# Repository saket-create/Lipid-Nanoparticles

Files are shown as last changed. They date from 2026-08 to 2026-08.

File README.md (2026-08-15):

# Lipid-Nanoparticles

This project focuses on developing a low-cost, lab-scale LNP manufacturing system using open-source hardware, 3D-printed components, and controlled multi-stream mixing.
this project is done in two steps:

**Semester Work**
This phase of the project involved developing the foundational process understanding through **simulation** and **flow diagram development**, along with research into **Process Analytical Technology (PAT)**. It also included the creation of the **P&ID** and completion of a preliminary **HAZOP analysis**, followed by the initial design of the mixing system and overall process layout.
A **Python library for LNP composition and process simulation** was also developed, incorporating different formulation variations along with a user manual for the simulation tools.

**Summer Work**
In this section i introduced the theoretical part to applied lab where I proceed with **Fabrication and assembly** of four syringe pumps based on the Poseidon open-source design, integrated with an **Arduino, CNC Shield V3, and A4988 stepper motor** drivers using the AccelStepper library for precise control. The work also included **experimental calibration of syringe pump** flow rates, where different settings were tested and tuned to achieve consistent output, along with the design and 3D printing of a **Multi-Inlet Vortex Mixer (MIVM)** to improve mixing efficiency. The system was further refined through iterative testing, troubleshooting, and optimization of both pumping and mixing performance, with each iteration helping to improve accuracy, stability, and overall system reliability.

This repository contains the **CAD files, Arduino code, experimental data, process documentation, and project resources** developed throughout the project. It serves as a project record, technical handover, and portfolio of the work.

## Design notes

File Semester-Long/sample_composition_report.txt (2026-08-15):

  LNP COMPOSITION & MASS REPORT
  Run ID : 050    |    Timestamp : 2026-04-06  09:04:29
  Calculation mode : FORWARD (feed streams → derived streams)

  mass_flow (mg/min) = concentration (mg/mL) x flow_rate (mL/min)
  TFF separation uses realistic efficiency fractions (see table below).

  TFF SEPARATION EFFICIENCIES
  Component                             Retained (retentate)   Removed (permeate)
  Cholesterol                                            98%                   2%
  Citric Acid                                             2%                  98%
  DSPC (Phospholipid)                                    98%                   2%
  EDTA                                                    2%                  98%
  Ethanol                                                 5%                  95%
  Ionisable Lipid (SM-102/MC3)                           98%                   2%
  Dibasic Sodium Phosphate                                2%                  98%
  Sodium Chloride (NaCl)                                  2%                  98%
  Monobasic Sodium Phosphate                              2%                  98%
  PEG-DMG / PEG-Lipid                                    98%                   2%
  Sodium Citrate                                          2%                  98%
  Water                                                  10%                  90%
  mRNA                                                   95%                   5%

  AQUEOUS PHASE  (mRNA + Buffer, Pump P-101)
  Flow rate : 9.0000 mL/min

  Component                             Conc (mg/mL)   Mass Flow (mg/min)  Source
  mRNA                                        0.1000               0.9000  (user input)
  Citric Acid                                 8.4000              75.6000  (user input)
  Sodium Citrate                              5.9000              53.1000  (user input)
  EDTA                                        0.1900               1.7100  (user input)
  Water                                     985.0000            8865.0000  (user input)

  ORGANIC PHASE  (Lipids in Ethanol, Pump P-102)
  Flow rate : 3.0000 mL/min

  Component                             Conc (mg/mL)   Mass Flow (mg/min)  Source
  Ionisable Lipid (SM-102/MC3)               10.0000              30.0000  (user input)
  DSPC (Phospholipid)                         2.5900               7.7700  (user input)
  Cholesterol                                 1.4800               4.4400  (user input)
  PEG-DMG / PEG-Lipid                         0.4500               1.3500  (user input)
  Ethanol                                   789.0000            2367.0000  (user input)

  DILUTION BUFFER  (PBS / Buffer, T-105)
  Flow rate : 36.0000 mL/min

  Component                             Conc (mg/mL)   Mass Flow (mg/min)  Source
  Sodium Chloride (NaCl)                      8.0000             288.0000  (user input)
  Dibasic Sodium Phosphate                    1.4400              51.8400  (user input)
  Monobasic Sodium Phosphate                  0.2400               8.6400  (user input)
  Water                                     990.0000           35640.0000  (user input)

  CRYOPROTECTANT FEED  (Trehalose/Sucrose, T-100)
  Flow rate : 0.5000 mL/min

  Component                             Conc (mg/mL)   Mass Flow (mg/min)  Source
  Trehalose / Sucrose (Cryoprotectant)       200.0000             100.0000  (user input)
  Water                                     800.0000             400.0000  (user input)

  MIXER OUTPUT  (Crude LNP Dispersion, M-101)
  Flow rate : 12.0000 mL/min

  Component                             Conc (mg/mL)   Mass Flow (mg/min)  Source
  Cholesterol                                 0.3700               4.4400  (calculated)
  Citric Acid                                 6.3000              75.6000  (calculated)
  DSPC (Phospholipid)                         0.6475               7.7700  (calculated)
  EDTA                                        0.1425               1.7100  (calculated)
  Ethanol                                   197.2500            2367.0000  (calculated)
  Ionisable Lipid (SM-102/MC3)                2.5000              30.0000  (calculated)
  PEG-DMG / PEG-Lipid                         0.1125               1.3500  (calculated)
  Sodium Citrate                              4.4250              53.1000  (calculated)
  Water                                     738.7500            8865.0000  (calculated)
  mRNA                                        0.0750               0.9000  (calculated)

  TFF RETENTATE  (Purified Concentrated LNP, UF-101)
  Flow rate : 8.0000 mL/min

  Component                             Conc (mg/mL)   Mass Flow (mg/min)  Source
  Cholesterol                                 0.5439               4.3512  (calculated)
  Citric Acid                                 0.1890               1.5120  (calculated)
  DSPC (Phospholipid)                         0.9518               7.6146  (calculated)
  EDTA                                        0.0043               0.0342  (calculated)
  Ethanol                                    14.7937             118.3500  (calculated)
  Ionisable Lipid (SM-102/MC3)                3.6750              29.4000  (calculated)
  Dibasic Sodium Phosphate                    0.1296               1.0368  (calculated)
  Sodium Chloride (NaCl)                      0.7200               5.7600  (calculated)
  Monobasic Sodium Phosphate                  0.0216               0.1728  (calculated)
  PEG-DMG / PEG-Lipid                         0.1654               1.3230  (calculated)
  Sodium Citrate                              0.1327               1.0620  (calculated)
  Water                                     556.3125            4450.5000  (calculated)
  mRNA                                        0.1069               0.8550  (calculated)

  TFF PERMEATE  (Waste Stream, UF-101)
  Flow rate : 40.0000 mL/min

  Component                             Conc (mg/mL)   Mass Flow (mg/min)  Source
  Cholesterol                                 0.0022               0.0888  (calculated)
  Citric Acid                                 1.8522              74.0880  (calculated)
  DSPC (Phospholipid)                         0.0039               0.1554  (calculated)
  EDTA                                        0.0419               1.6758  (calculated)
  Ethanol                                    56.2162            2248.6500  (calculated)
  Ionisable Lipid (SM-102/MC3)                0.0150               0.6000  (calculated)
  Dibasic Sodium Phosphate                    1.2701              50.8032  (calculated)
  Sodium Chloride (NaCl)                      7.0560             282.2400  (calculated)
  Monobasic Sodium Phosphate                  0.2117               8.4672  (calculated)
  PEG-DMG / PEG-Lipid                         0.0007               0.0270  (calculated)
  Sodium Citrate                              1.3009              52.0380  (calculated)
  Water                                    1001.3625           40054.5000  (calculated)
  mRNA                                        0.0011               0.0450  (calculated)

  FINAL PRODUCT  (Sterile LNP Formulation, ST-101)
  Flow rate : 8.0000 mL/min

  Component                             Conc (mg/mL)   Mass Flow (mg/min)  Source
  Cholesterol                                 0.5439               4.3512  (calculated)
  Citric Acid                                 0.1890               1.5120  (calculated)
  DSPC (Phospholipid)                         0.9518               7.6146  (calculated)
  EDTA                                        0.0043               0.0342  (calculated)
  Ethanol                                    14.7937             118.3500  (calculated)
  Ionisable Lipid (SM-102/MC3)                3.6750              29.4000  (calculated)
  Dibasic Sodium Phosphate                    0.1296               1.0368  (calculated)
  Sodium Chloride (NaCl)                      0.7200               5.7600  (calculated)
  Monobasic Sodium Phosphate                  0.0216               0.1728  (calculated)
  PEG-DMG / PEG-Lipid                         0.1654               1.3230  (calculated)
  Sodium Citrate                              0.1327               1.0620  (calculated)
  Trehalose / Sucrose (Cryoprotectant)        12.5000             100.0000  (calculated)
  Water                                     606.3125            4850.5000  (calculated)
  mRNA                                        0.1069               0.8550  (calculated)

  COMPONENT-WISE MASS BALANCE  (TFF level: inputs = retentate + permeate)

  Component                                Mass In     Mass Out      Error  Status
  Cholesterol                               4.4400       4.4400     0.0000  PASS
  Citric Acid                              75.6000      75.6000     0.0000  PASS
  DSPC (Phospholipid)                       7.7700       7.7700     0.0000  PASS
  EDTA                                      1.7100       1.7100     0.0000  PASS
  Ethanol                                2367.0000    2367.0000     0.0000  PASS
  Ionisable Lipid (SM-102/MC3)             30.0000      30.0000     0.0000  PASS
  Dibasic Sodium Phosphate                 51.8400      51.8400     0.0000  PASS
  Sodium Chloride (NaCl)                  288.0000     288.0000     0.0000  PASS
  Monobasic Sodium Phosphate                8.6400       8.6400     0.0000  PASS
  PEG-DMG / PEG-Lipid                       1.3500       1.3500     0.0000  PASS
  Sodium Citrate                           53.1000      53.1000     0.0000  PASS
  Water                                 44505.0000   44505.0000     0.0000  PASS
  mRNA                                      0.9000       0.9000     0.0000  PASS

  Mass balance: ALL COMPONENTS BALANCED

  END OF COMPOSITION REPORT

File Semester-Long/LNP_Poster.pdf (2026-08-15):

# Developing a Process Simulation Model for Lipid Nano-particle Manufacturing

## Aman Bola 24110032 | Rhythem Soni 24110296 | Saket Jonwal 24110311 Supervisor: Professor Kaustubh S. Rane

### Motivation & Background

mRNA vaccines (Pfizer-BioNTech, Moderna) saved millions of lives. Their secret ingredient: Lipid Nanoparticles (LNPs) - tiny spheres that protect and deliver mRNA into human cells.

### Lipid Nano-particles

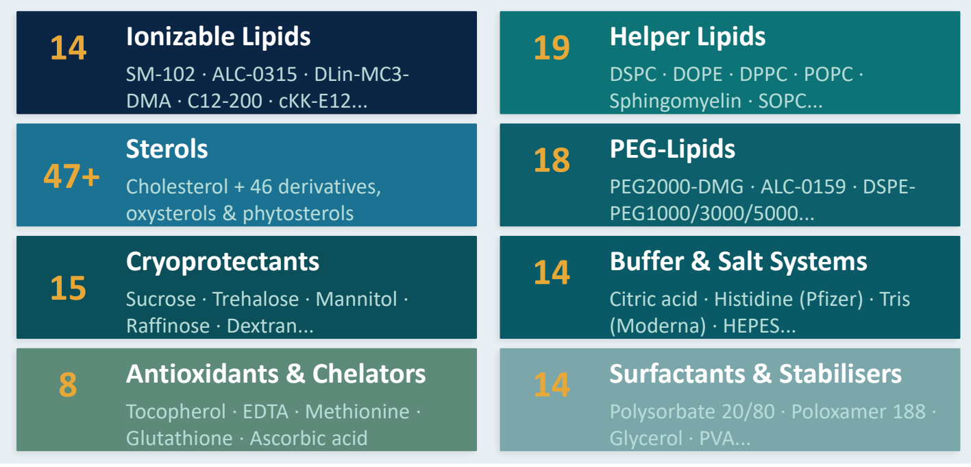
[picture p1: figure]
Ionizable Lipids; SM-102 · ALC-0315 · DLin-MC3- DMA · C12-200 · cKK-E12...; Helper Lipids; DSPC · DOPE · DPPC · POPC · Sphingomyelin · SOPC...; Sterols; Cholesterol + 46 derivatives, oxysterols & phytosterols; PEG-Lipids; PEG2000-DMG · ALC-0159 · DSPE- PEG1000/3000/5000...; Cryoprotectants; Sucrose · Trehalose · Mannitol · Raffinose · Dextran...; Buffer & Salt Systems; Citric acid · Histidine (Pfizer) · Tris (Moderna) · HEPES...; Antioxidants & Chelators; Tocopherol · EDTA · Methionine · Glutathione · Ascorbic acid; Surfactants & Stabilisers; Polysorbate 20/80 · Poloxamer 188 · Glycerol · PVA...

### Process Analytical Technology (PAT)

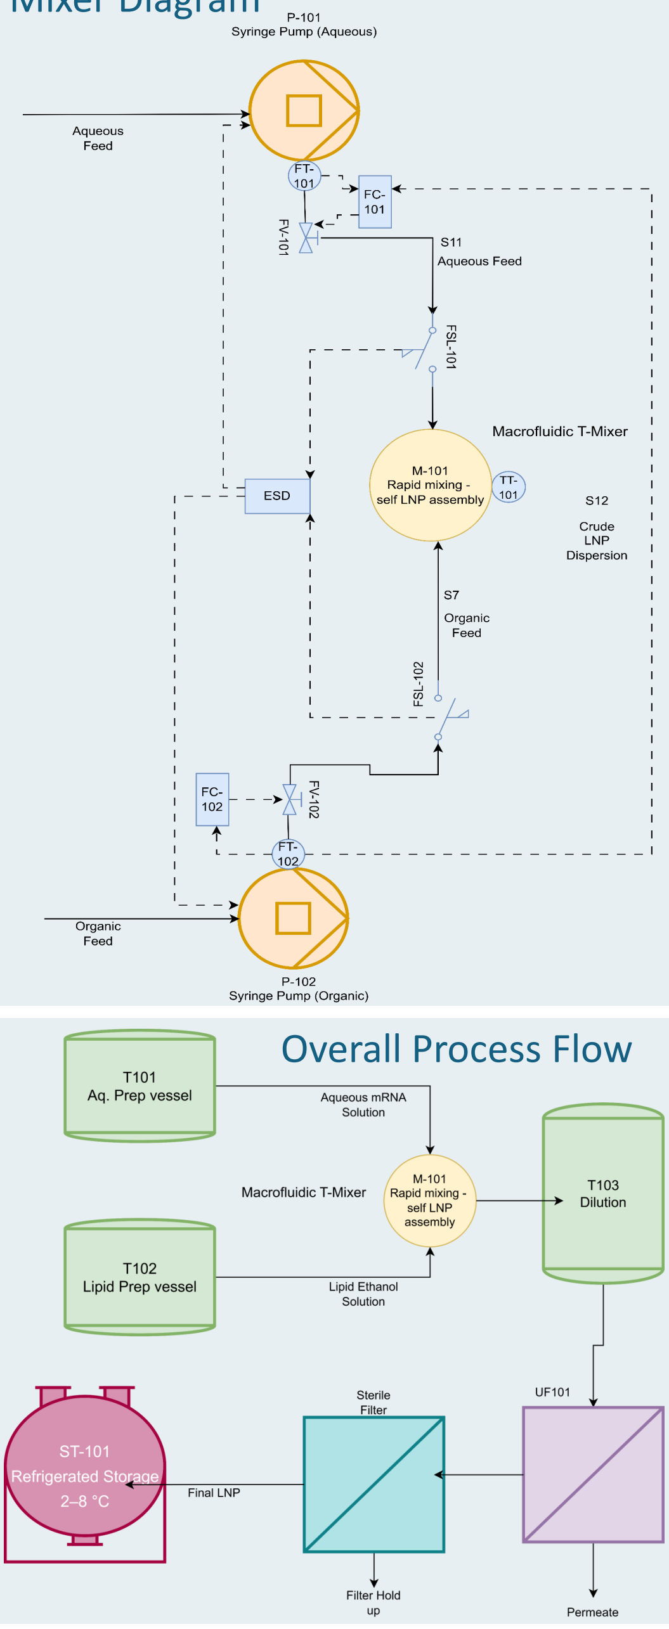
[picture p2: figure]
Overall Process Flow

The FDA defines PAT as a system to analyze, monitor, and control pharmaceutical manufacturing processes in real time. We applied PAT by designing a P&ID with real control loops not just offline testing.

### Challenges

LNP production involves dozens of interlinked variables-flow rates, lipid ratios, pH, filtration pressures - making it extremely complex to design and scale up. So, we need an easy-to-use tool to calculate all process quantities.

### Our Solution

We built a process simulation model that handles all these calculations for you.

- LNPs are tiny, spherical particles made of lipids of size - (10nm - 100nm).
- They encapsulate and protect fragile molecules like mRNA to reach and enter in cells efficiently.
- Ionizable lipid: binds RNA and enables endosomal escape.
- Phospholipid: provides structural stability.
- Cholesterol: improve membrane rigidity and integrity.
- PEG-lipid: prevents aggregation and improves circulation time.

### LNP Component Library (150+ Compounds)

We catalogued every compound used in LNP manufacturing from published patents and scientific literature, with molecular weights and clinical annotations:

FOUR MEASUREMENT LEVELS:

INLINE

Real-time, no sample removal.
Eg: DLS, Zeta potential ,pH sensor, Conductivity, Flow meter, Temperature probes, Pressure probs.

ONLINE

ATLINE

OFFLINE

Near real-time, automated sample removal
Eg: HPLC, Raman spectroscopy, LC-MS, UV diode array. Manual sample removal near production line.
Eg: DLS, Zeta potential, NMR.
Sample removed to separate lab.
Eg: Cryo-TEM.

Focus on identifying two basis:
1) CQAs (Critical Quality Attributes). Eg: Size <100 nm, PDI <0.3.
2) CPPs (Critical Process Parameters). Eg: Flow, Temperature, Pressure etc.

### Key Software Feature

Three Calculation Modes: FORWARD (feeds → product), BACKWARD (desired product → required feeds), or BOTH simultaneously.

DOF Analysis: Automatically checks the Degrees of Freedom. Alerts user if the system is under- or over-specified before solving.

Self-Consistency Check: If concentration AND mass flow are both given for the same component, the software verifies they are consistent with the flow rate.

Warnings & Validation: Flags physically impossible values (e.g. negative flows), out-of-range conditions, and concentration/mass mismatches with severity levels.
Material Balance Verification: Checks that total mass IN equals total mass OUT for every component at TFF level. Reports PASS/FAIL per component. Knowability Scoring: In over-determined cases, automatically selects which variable to treat as redundant, based on how directly measurable each is.

Run History & Reports: Every run is saved in a timestamped folder: output report, diagnostics file, and a copy of the input used.

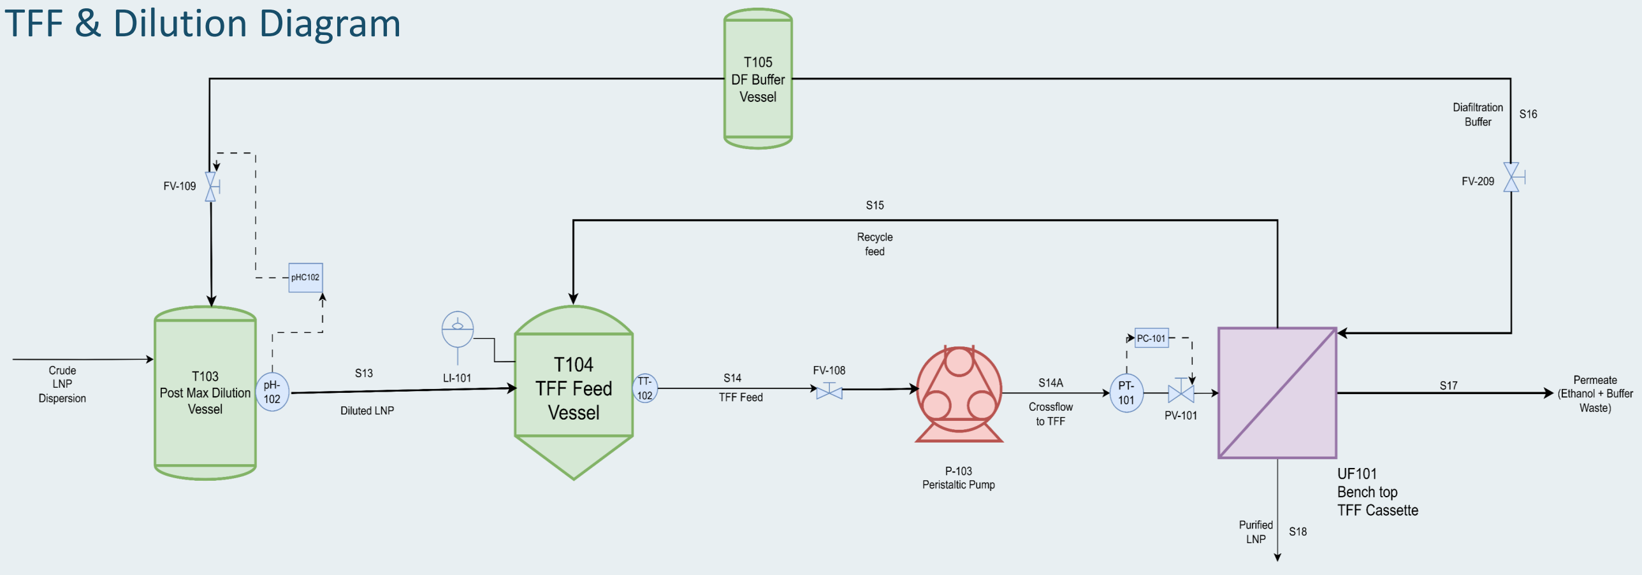
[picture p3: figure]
TFF & Dilution Diagram

### Future Work

- Particle Size Prediction: Add empirical correlations: FRR + total flow rate →
predicted | LNP | size | and | PDI.
- Experimental Validation: Verify all model predictions against physical LNP synthesis runs in the laboratory.
- Digital Twin: Connect PAT sensor feeds to simulation in real-time - close the loop between model and process.
- DoE Optimisation Module: Automated formulation screening → find optimal lipid ratios for target CQAs.
- Scale-Up Calculator: Extend from lab syringe pumps to industrial IJM (KNAUER) and NxGen (Precision Nanosystems) systems.

### Acknowledgement

We are sincerely grateful to our supervisor, Prof. Kaustubh S. Rane, for his invaluable guidance and mentorship.

### Mixer Diagram

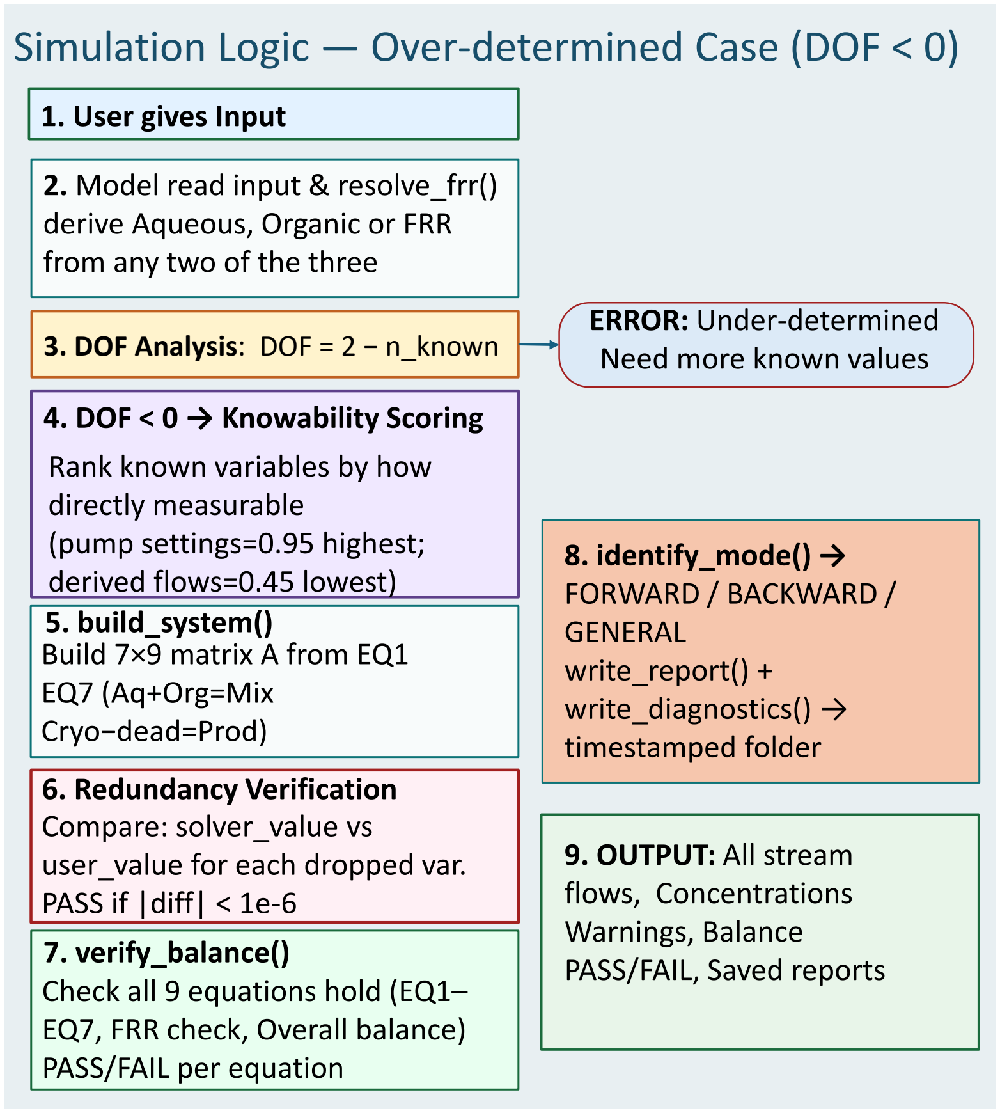
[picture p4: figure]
1. User gives Input; 2. Model read input & resolve_frr() derive Aqueous, Organic or FRR from any two of the three; 3. DOF Analysis: DOF = 2 − n_known; ERROR: Under-determined Need more known values; 4. DOF < 0 → Knowability Scoring; Rank known variables by how directly measurable (pump settings=0.95 highest; derived flows=0.45 lowest) 5. build_system() Build 7×9 matrix A from EQ1 EQ7 (Aq+Org=Mix Cryo−dead=Prod); 6. Redundancy Verification Compare: solver_value vs user_value for each dropped var. PASS if |diff| < 1e-6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

### Simulation Logic — Over-determined Case (DOF < 0)

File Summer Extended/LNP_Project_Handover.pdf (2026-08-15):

# Lab-Scale Lipid Nanoparticle (LNP) Manufacturing

## Project Document

Indian Institute of Technology Gandhinagar Supervisor: Prof. Kaustubh S. Rane Team: Aman Bola 24110032,
Rhythem Soni 24110296,
Saket Jonwal 24110311

Purpose of this document: This document records what has been done on this project to date, why each decision was made, what data/resources exist, and what the open problems and recommended next steps are.

## 1. Project Overview

The goal of this project is to build a lab-scale, low-cost manufacturing setup for lipid nanoparticles (LNPs) using microfluidic mixing. LNPs are the delivery vehicles used for mRNA vaccines and other nucleic-acid therapeutics, and their manufacture at lab scale conventionally relies on expensive commercial microfluidic systems (e.g. NanoAssemblr). The aim of this project is to replicate the core functionality of such a system, controlled multistream mixing of an aqueous phase and a lipid/ethanol phase using open-source hardware and 3D-printed parts, so that LNP formulation work can be done in-house at a fraction of the cost.

The overall system has two halves that had to be built in parallel:

- A set of syringe pumps that can deliver precise, controllable, pulsation-free flow rates for each inlet stream.
- A mixer geometry (the actual mixing chamber) that brings the streams together under turbulent/vortex conditions so that nanoprecipitation happens reproducibly.
Below is a chronological account of the work, organized by workstream.

## 2. Process Simulation Model and Process Flow Diagram

Early in the project, a process simulation model was built to map out the overall LNP manufacturing process conceptually (feed streams, mixing step, downstream dialysis/purification, and characterization steps) before committing to hardware. The process simulation model is there in the final_zip.zip file and you can find it in the google drive. There is a detailed user manual in it which will give complete detail about the model.

A process flow diagram (PFD) of the full process was also created, drawn using draw.io. This PFD is the singlepage reference for how material flows through the system end-to-end (solvent/antisolvent prep → pumps → mixer → collection → downstream processing) and should be consulted first by anyone new to the project to understand where the hardware described in this document sits in the overall workflow. It is also attached in the google drive.

## 3. Process Analytical Technology (PAT) Research

Before finalizing the hardware approach, the team researched Process Analytical Technology (PAT), the general framework (promoted heavily by FDA/ICH guidance for pharmaceutical manufacturing) of building measurement and control directly into a process rather than relying purely on end-product testing. For LNP manufacturing specifically, this means thinking about in-line or at-line monitoring of things like flow rate, particle size (e.g. via in-line DLS), and mixing quality, rather than only characterizing the final product after the fact.

This research shaped two decisions downstream: (1) the emphasis on rigorously calibrating flow rate at the pump level rather than trusting motor step counts blindly, and (2) keeping the mixer design modular enough that in-line sensors could plausibly be added later (e.g. at the outlet tubing).

## 4. Syringe Pump Development

## 4.1 Reference design: Poseidon Github Repository

The syringe pump hardware is based on the open-source Poseidon syringe pump project. This was chosen over designing a pump from scratch because it is a mature, well-documented open-source design with an existing STL/CAD library and firmware base, which significantly reduced development time.

Repository link: https://github.com/pachterlab/poseidon/tree/release

## 4.2 Fabrication

- The Poseidon pump body and carriage parts were 3D printed in the Tinkerer’s Lab.
- Remaining mechanical/electrical components (leadscrews, couplers, NEMA stepper motors, linear rods/bearings, CNC Shield V3 boards, A4988 stepper drivers, Arduino Uno/Nano boards, CH340-based USB-serial boards) were ordered. We have attached the purchase list in the google drive for further reference.
- Four pump units were assembled in total, following the Poseidon assembly instructions, to eventually supply the four inlets of the MIVM. There is a detailed video in the Poseidon repository for the assembly.
- NOTE: In google drive we have attached the modified base for syringe pump model as earlier it was facing screw fixing issues however for other parts to print you have to follow the Poseidon Github Repository.

## 4.3 Control electronics and firmware

Each pump is driven by an Arduino + CNC Shield V3 + A4988 driver stack, controlled using the AccelStepper library for smooth, non-blocking acceleration/deceleration motion profiles. Firmware was written so that a controlling PC can send serial commands (move-to targets, speed) and the pump executes them. The code for Arduino is attached in the google drive (for only X and Z axis of CNC shield and for all four connection you need to repeat the same code for Y and A axis).

Two of the four pumps have been calibrated so far (see Section 5); the other two are built but calibration is still pending because those two motors were not good.

## 5. Syringe Pump Calibration

Calibration methodology: flow rate was determined gravimetrically rather than by trusting the theoretical steps-permL conversion computed from syringe diameter and leadscrew pitch. This mirrors the calibration approach described in the referenced eNeuro paper (ENEURO.0240-19.2019), which was used as a methodological reference for how to rigorously validate syringe-pump flow rate against motor step rate.

The general procedure used for each calibration run:

- The acceleration and the maximum speed parameters (steps/sec² and steps/sec, set in the AccelStepper firmware) were kept fixed for a given pump; the actual run speed for each trial was set at or below this ceiling.
- The pump was run to dispense water into a pre-weighed vessel.
- The mass of water dispensed was measured directly using a weighing machine.
- The time taken to dispense that water was measured independently using a stopwatch.
- Flow rate was then calculated from these two measurements using the mass–density–volume relation (volume = mass / density of water, at ~0.976 g/mL, temperature-adjusted) and flow rate = volume / time.
- This was repeated across a range of run speeds, from ~420 steps/sec up to ~1050 steps/sec, to build a speed → flow-rate calibration curve for each pump.
The calibration data for both the pumps is attached in the google drive in the form of excel sheets.

Observed working range: at the acceleration setting used (200 steps/sec²), motor speeds from ~420 to ~1050 steps/sec produced flow rates from roughly 63 mL/min to 140 mL/min on the calibrated pumps. The relationship between speed and flow rate is close to linear over this range but should be fitted properly (linear regression) rather than assumed, and re-validated whenever syringe diameter, leadscrew, or tubing is changed.

Note: the literature-recommended per-inlet flow rate range for MIVM operation, per Markwalter & Prud'homme (2018) and Zhang & Clapp (2014), is 20–125 mL/min; the target total flow rate (TFR) for our MIVM is 250–300 mL/min across four inlets. This means the pumps need to be run well down their speed range (not near the top of the ~420–1050 steps/sec range tested) to hit realistic per-inlet flow rates for LNP formulation trials.

Important limitation: calibration in the literature-relevant 20–125 mL/min range has not yet been completed. At the lower speeds this range corresponds to, the pump produced noticeable jerking. The root cause identified was that the syringe available was slightly larger than the pump model's syringe holder was designed for, so it had to be forced into place; this small dimensional mismatch is what produces the jerking, and it becomes more noticeable at lower speeds. The fix identified (but not yet carried out) is to rub the syringe holder area of the printed pump model by sanding or filing it down with sandpaper or a metal file so the minor dimensional excess is removed and the syringe seats properly without being forced. Once this is done, the pump should run smoothly at lower speeds, and calibration in the actual 20–125 mL/min operating range should be carried out as a priority.

A separate vibration issue was also observed with the pump body during operation. This was resolved (as a practical fix, not a design fix) by applying double-sided tape to the underside of the pump base and mounting the pump on a rubber sheet, which damps the vibration. This fix should be replicated across all four pump units.

## 6. Micromixer Development

## 6.1 Initial approach: Y/T-mixer

The first mixer concept explored was an open-groove Y-mixer / T-mixer design. This was abandoned because it requires microchannels (sub-mm scale) to achieve adequate mixing, and the campus 3D printers available to the team could not reliably resolve channels at that scale, prints either failed to resolve the channel geometry or produced channels too rough/blocked to be usable.

## 6.2 Shift to MIVM (Multi-Inlet Vortex Mixer)

Given the fabrication constraint above, the design was shifted to a Confined Impinging Jets (CIJ) / Multi-Inlet Vortex Mixer (MIVM) design, which achieves rapid turbulent mixing in a larger, more printable chamber (mm-scale rather than sub-mm channels), while still giving the mixing intensity needed for nanoprecipitation.

The design mainly follows: Markwalter, C.E. & Prud'homme, R.K., "Design of a Small-Scale Multi-Inlet Vortex Mixer for Scalable Nanoparticle Production and Application to the Encapsulation of Biologics by Inverse Flash NanoPrecipitation," J. Pharm. Sci. (2018), the supplementary information document supplied with this handover (1-s2_0-S0022354918303071-mmc1.docx).

## 6.3 Scaling the dimensions

The supplementary information provides dimensions for the small μMIVM design (chamber diameter 0.5 cm, channel height/width 0.075 cm each), plus dimensions for the original, larger benchtop MIVM (chamber diameter 0.6 cm, channel height 0.15 cm). It also gives the scaling relation used to relate chamber diameter to channel width across mixer sizes:

Dc1² / w1 = Dc2² / w2 (Eqn. S1, Markwalter & Prud'homme 2018)

where subscript 1 refers to the original MIVM and subscript 2 refers to the scaled (μMIVM-style) design. This relation was used to back-calculate a self-consistent set of dimensions for our printable mixer, since the paper's exact μMIVM channel width (0.75 mm) was still below our printer's reliable minimum feature size.

The Autodesk file for the mixer model is attached in the google drive and you can we have also made some variations in a few dimensions which you can see from the 3D model.

Target operating point for this geometry: total flow rate (TFR) of 250–300 mL/min split across the four inlets.

## 6.4 Fabrication and materials

The mixer was 3D printed in PETG. PETG was chosen after researching solvent compatibility with pure ethanol (the typical organic/lipid-carrying solvent stream), drawing on Kaptan (2025), Grzelak (2021), Roberson (2019), Plaskolite's TEC409 chemical resistance data, and ORNL/TM-2012/88: PETG shows good short-to-medium-term resistance to ethanol at the concentrations and contact times relevant here.

## 7. Current Status and Open Issues

## 7.1 Syringe pump hardware/firmware

- Only 2 of 4 pumps are calibrated, and even that calibration only covers ~420–1050 steps/sec — it does not yet cover the literature-relevant 20–125 mL/min per-inlet range, because of the syringe-fit jerking issue described in Section 5. Fixing the syringe holder fit (sanding/filing) and then calibrating at lower speeds is a priority open task.
- The acceleration and the deceleration part is not accounted for in the calibration. That means the pump does not operate at constant speed throughout. Instead, it first accelerated, then moved at constant speed, and then it decelerated to stop. So, this acceleration/deceleration time needs to be calibrated.

## 7.2 Mixer

- There are leakages observed in the mixer model which need to be solved by applying a proper sealant.

## 8. Key References and Resources

- Poseidon open-source syringe pump project (GitHub): (https://github.com/pachterlab/poseidon/tree/release) mechanical/firmware base for all four pumps.
- eNeuro paper, ENEURO.0240-19.2019: (https://www.eneuro.org/content/6/5/ENEURO.0240-19.2019#abstract-1) reference for gravimetric syringe pump calibration methodology.
- Markwalter, C.E. & Prud'homme, R.K. (2018), "Design of a Small-Scale Multi-Inlet Vortex Mixer for Scalable Nanoparticle Production and Application to the Encapsulation of Biologics by Inverse Flash NanoPrecipitation," Journal of Pharmaceutical Sciences: primary reference for MIVM geometry and scaling relation (Eqn. S1). Supplementary info attached as 1-s2_0-S0022354918303071-mmc1.docx.
- Zhang, C. & Clapp, T. (2014): cross-reference for MIVM per-inlet flow rate operating ranges.
- Kaptan (2025), Grzelak (2021), Roberson (2019), Plaskolite TEC409, ORNL/TM-2012/88: PETG chemical/solvent-compatibility references used to justify PETG as the mixer print material.
- Process flow diagram: draw.io
- Process simulation model
- Raw calibration data: calibration_model_C.xlsx and calibration_model_unlabelled.xlsx

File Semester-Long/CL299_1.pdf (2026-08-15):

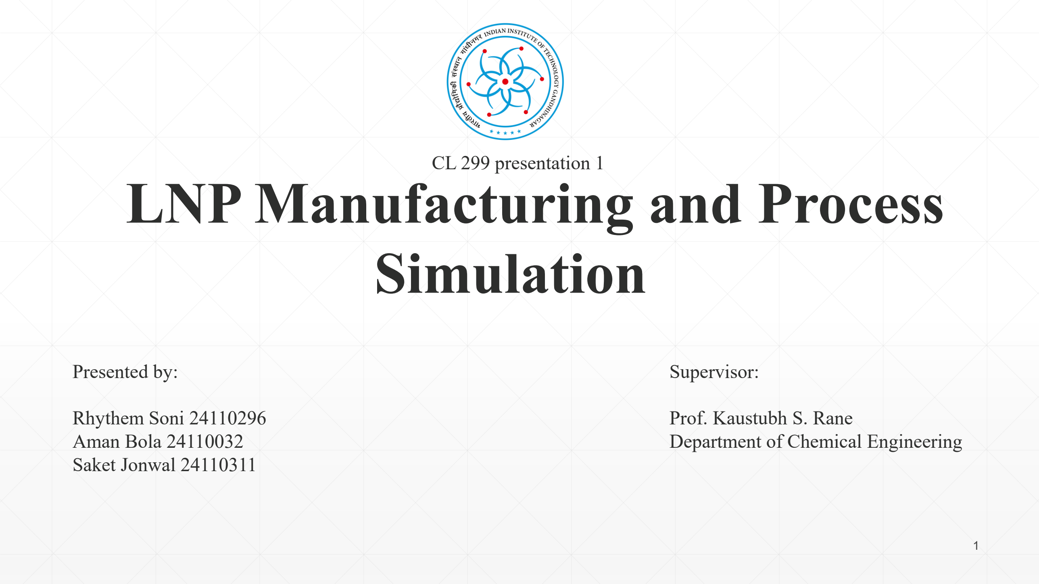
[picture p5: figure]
LNP Manufacturing and Process Simulation; CL 299 presentation 1; Supervisor:; Prof. Kaustubh S. Rane Department of Chemical Engineering; Presented by:; Rhythem Soni 24110296 Aman Bola 24110032 Saket Jonwal 24110311

# MOTIVATION AND BACKGROUND

- Rapid success of mRNA vaccines. (Eg: Pfizer-BioNTech and Moderna).
- Directly injected mRNA would be rapidly degraded by enzymes in the body before it can reach and enter cells.
- LNPs are the industry-standard delivery system for mRNA.
- Major challenges: scalability, reproducibility and controllable manufacturing of LNPs.
- Commercial manufacturing requires tight control on size and uniformity.

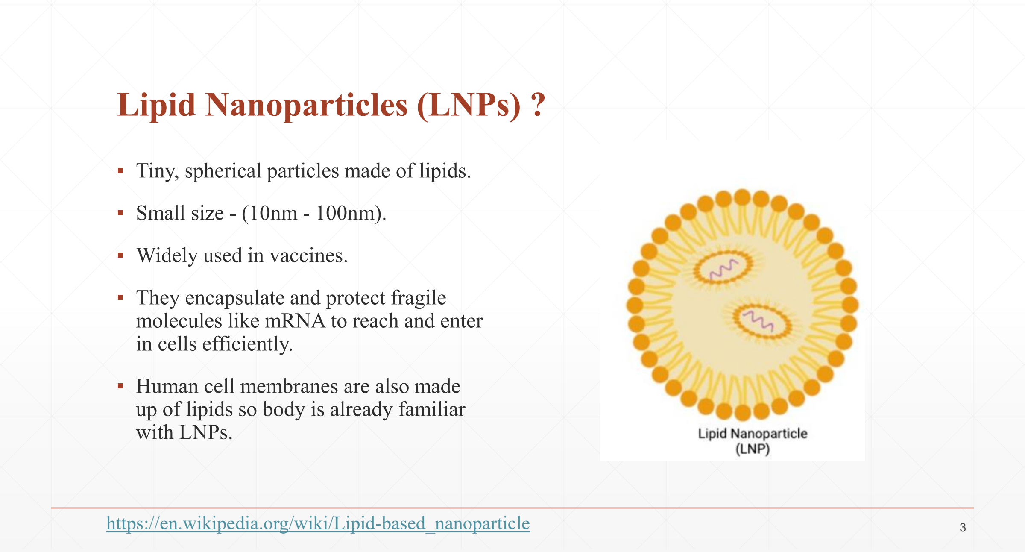
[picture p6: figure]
Lipid Nanoparticles (LNPs) ?; ▪ Small size - (10nm - 100nm).; ▪ Widely used in vaccines.; ▪ They encapsulate and protect fragile molecules like mRNA to reach and enter in cells efficiently.; ▪ Human cell membranes are also made; with LNPs.; https://en.wikipedia.org/wiki/Lipid-based_nanoparticle

- Tiny, spherical particles made of lipids.

up of lipids so body is already familiar

# Before LNPs → Liposomes

Liposomes are spherical vesicles composed of one or more phospholipid bilayers enclosing an aqueous core.

•Liposomes were the first clinically successful lipid-based nanocarriers.
•Widely used for small molecules, proteins, and early nucleic acid delivery.

Why liposomes were originally used for nucleic acids :-

•Phospholipid bilayers are biocompatible
•Can encapsulate hydrophilic cargo (DNA/RNA) in aqueous core •Protect cargo from enzymatic degradation

https://en.wikipedia.org/wiki/Lipid-based_nanoparticle

# Disadvantages of liposomes for mRNA delivery

- Low mRNA encapsulation efficiency because liposomes rely on passive loading and lack strong electrostatic interaction with nucleic acids.
- Poor endosomal escape, resulting in degradation of mRNA before it reaches the cell.
- Limited scalability.

Why the field shifted from Liposomes to LNPs?

- Very high mRNA encapsulation efficiency (>90%) due to electrostatic complexation between ionizable lipids and negatively charged mRNA.
- Efficient endosomal escape enabled by ionizable lipids that become protonated at low pH and disrupt the endosomal membrane.
- Excellent scalability and reproducibility through continuous manufacturing methods (ethanol injection, microfluidics, jet/impingement mixing) with tight control of CQAs.

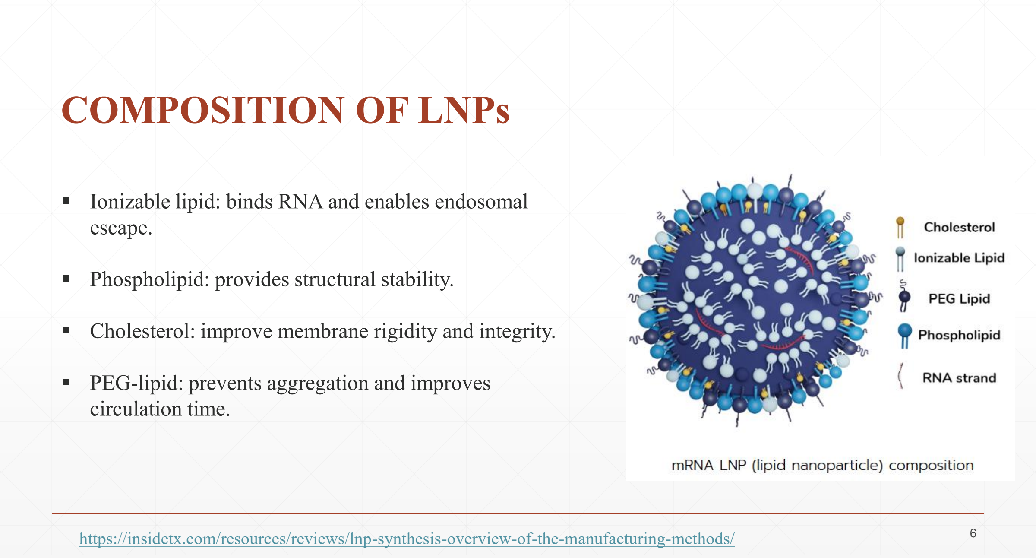
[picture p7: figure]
COMPOSITION OF LNPs; escape.; ▪ Phospholipid: provides structural stability.; circulation time.; https://insidetx.com/resources/reviews/lnp-synthesis-overview-of-the-manufacturing-methods/

- Ionizable lipid: binds RNA and enables endosomal
- Cholesterol: improve membrane rigidity and integrity.
- PEG-lipid: prevents aggregation and improves

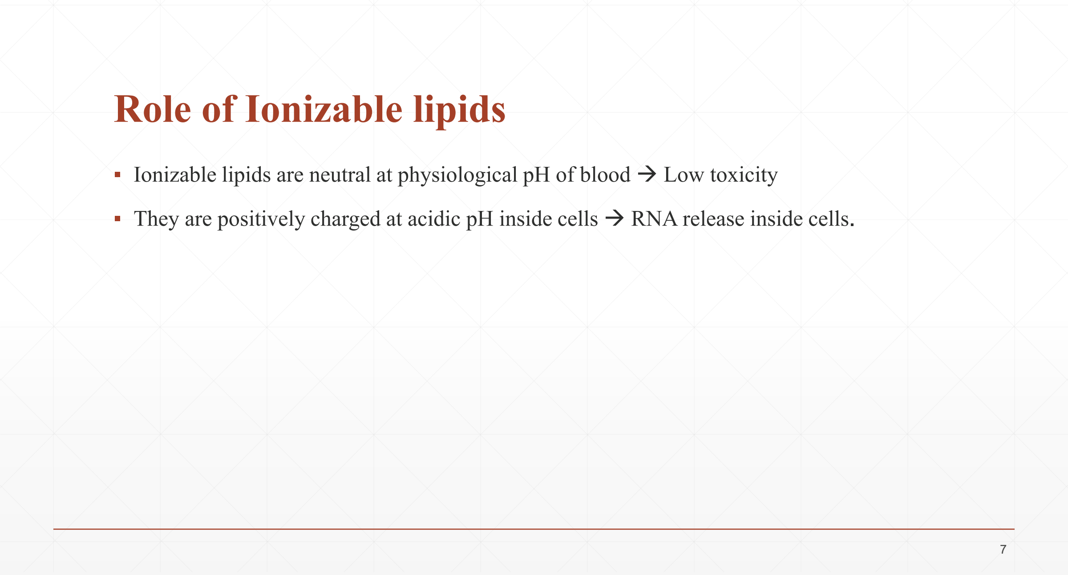
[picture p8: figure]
Role of Ionizable lipids

- Ionizable lipids are neutral at physiological pH of blood → Low toxicity
- They are positively charged at acidic pH inside cells → RNA release inside cells.

# LNP Formulation

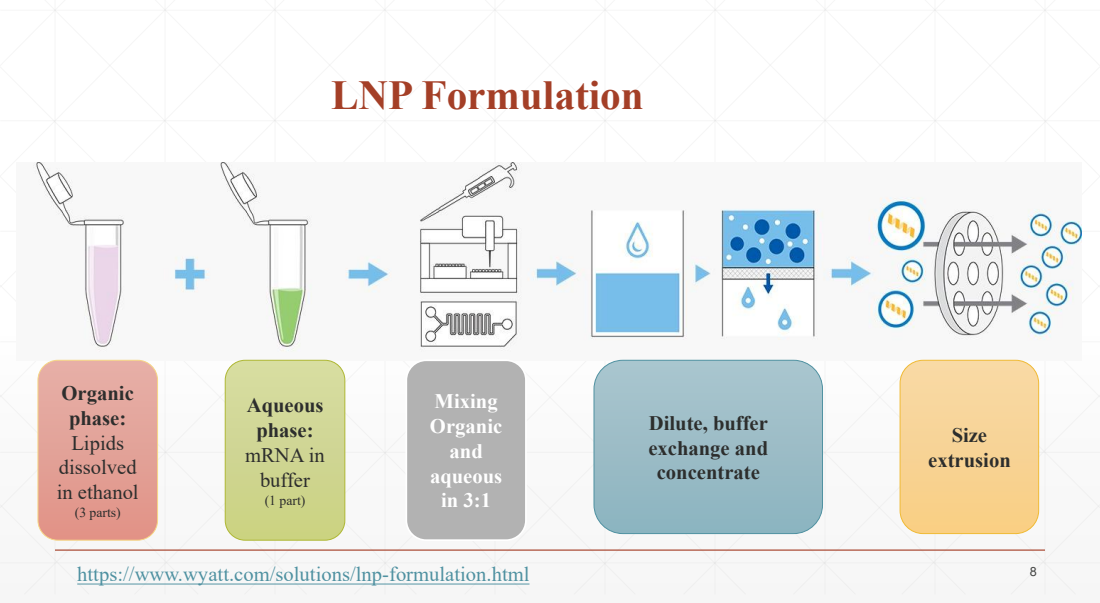
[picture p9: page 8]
Organic phase: Lipids dissolved in ethanol; (3 parts); Aqueous phase: mRNA in buffer; (1 part); Mixing Organic and aqueous in 3:1; Dilute, buffer exchange and concentrate; Size extrusion

8 https://www.wyatt.com/solutions/lnp-formulation.html

# LNP FORMULATION

- When Aqueous and organic phases are mixed, ethanol concentration suddenly drops.
- Rapid dilution of ethanol causes lipid oversaturation → lipids become insoluble.
- Lipids spontaneously self-assembled around mRNA.
- Process occurs within millisecond.

Hence, LNPs are formed.

# IMPORTANCE OF MIXING

- Particle size control and uniformity of LNPs are determined by mixing time.
- Mainly ensures a homogeneous temperature and mRNA concentration during formulation.
- Ensure high mRNA encapsulation efficiency → improve drug loading.
- The rate and manner of mixing directly affect self-assembly steps.
- Slow or uncontrolled mixing results in broad size distribution (high PDI).
- The faster the mixing the smaller the synthesized LNPs.

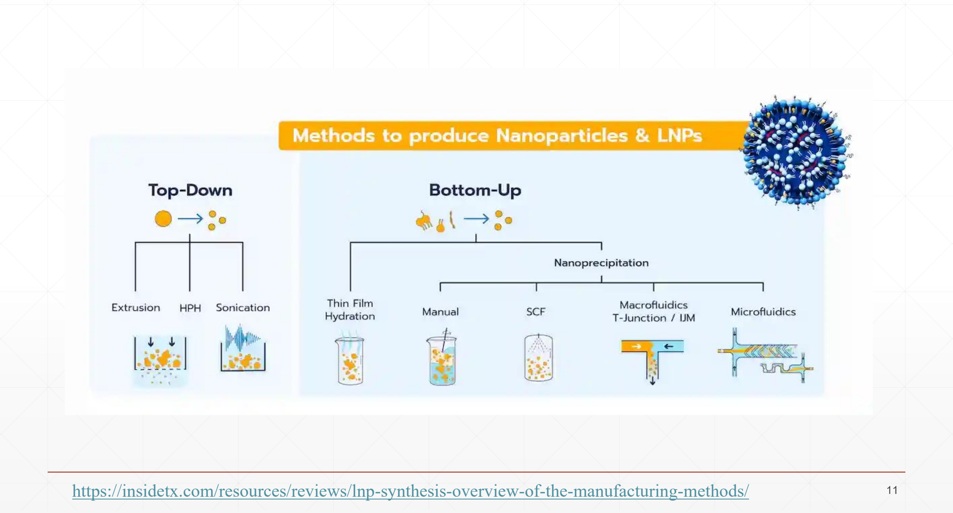
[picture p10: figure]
https://insidetx.com/resources/reviews/lnp-synthesis-overview-of-the-manufacturing-methods/

- Top-down methods: Also referred to as high-energy methods, these involve applying energy to break larger particles into smaller ones.
- Bottom-up methods: These rely on the self-assembly of lipid components to form homogeneous nanoparticle systems.

### High-Pressure Homogenization (HPH)

- Liquid is forced through a narrow valve at very high pressure, creating intense shear and turbulence for mixing.
- Droplet/particle size is reduced to the nanoscale due to shear, cavitation, and impact forces.
- Suitable for large-scale, continuous processing, but
involves high energy input.

12 https://www.researchgate.net/figure/Schematic-representation-of-the-high-pressure-homogenization-process-11_fig5_258392503

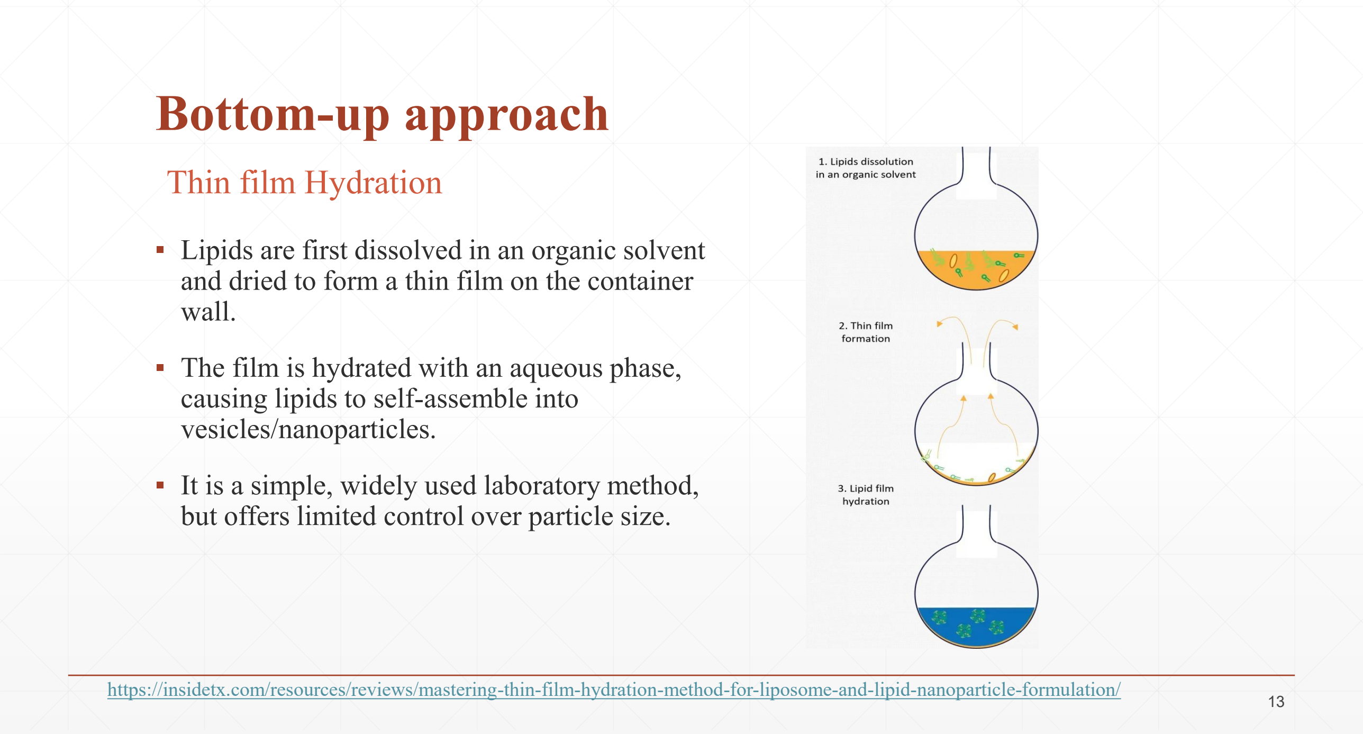
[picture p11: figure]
Bottom-up approach; wall.; causing lipids to self-assemble into vesicles/nanoparticles.; Thin film Hydration; 13 https://insidetx.com/resources/reviews/mastering-thin-film-hydration-method-for-liposome-and-lipid-nanoparticle-formulation/

- Lipids are first dissolved in an organic solvent and dried to form a thin film on the container
- The film is hydrated with an aqueous phase,
- It is a simple, widely used laboratory method, but offers limited control over particle size.

- Lipid and aqueous phases are mixed manually using pipetting or simple stirring.
- The process offers minimal control over mixing intensity and uniformity.
- Results in poor reproducibility and broad particle size distribution.
- Uses supercritical CO₂ as an antisolvent to mix with lipid solutions and induce nanoparticle formation.
- Enables rapid mixing with low residual organic solvent in the final product.
- Requires high-pressure, complex equipment, limiting routine use.

### Manual method

### Supercritical Fluid Methods (SCFs)

- Mixing occurs in millimeter-scale channels with controlled flow rates.
- Offers better control than batch/manual mixing but less precision than microfluidics.
- Suitable for higher throughput and easier scale-up compared to microfluidic systems.

Eg: Impingement Jet Mixing (IJM).

- Fluids are mixed in micron-scale channels under precisely controlled flow conditions.
- Provides highly uniform and reproducible nanoparticles with narrow size distribution.
- Ideal for formulation screening and early-stage development, though scale-up can be challenging.

Eg: NxGen Mixing Technology.

### Macrofluidics

### Microfluidics

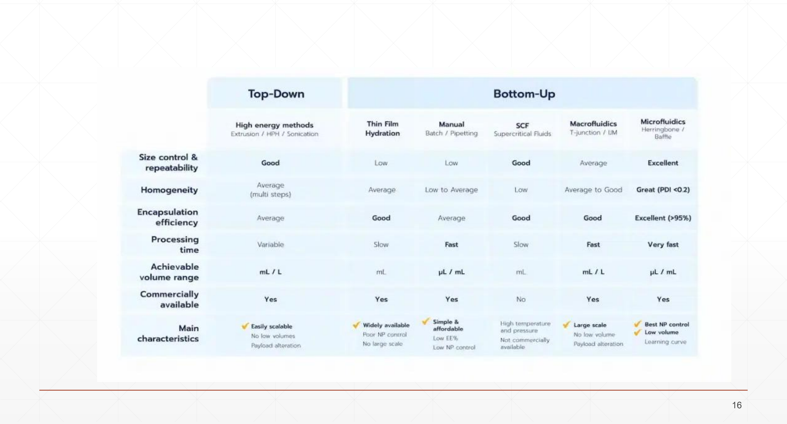
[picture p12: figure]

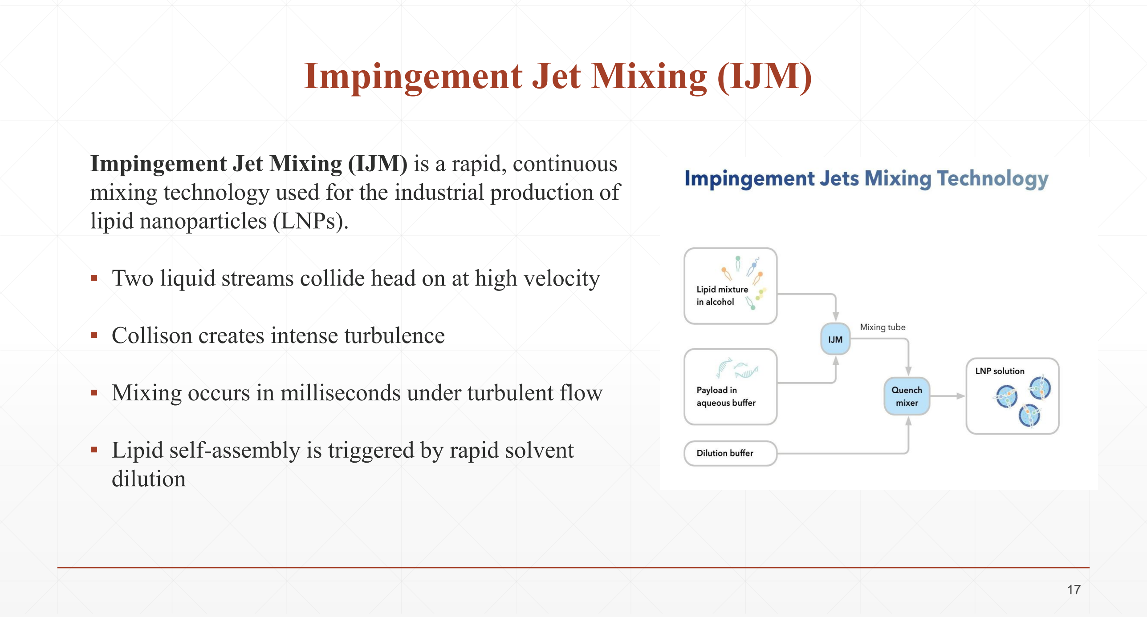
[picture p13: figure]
Impingement Jet Mixing (IJM); lipid nanoparticles (LNPs).; ▪ Collison creates intense turbulence; dilution

Impingement Jet Mixing (IJM) is a rapid, continuous mixing technology used for the industrial production of

- Two liquid streams collide head on at high velocity
- Mixing occurs in milliseconds under turbulent flow
- Lipid self-assembly is triggered by rapid solvent

## What happens inside the IJM chamber

- The two streams impinge directly at the mixing point
- High Reynolds number flow generates strong turbulence
- Turbulence eliminates concentration gradients instantly
- Ethanol concentration drops rapidly → lipid solubility collapses
- Nucleation :- Small lipid clusters form uniformly throughout the volume
- Growth arrest :- Fast quenching prevents uncontrolled aggregation

Encapsulation mechanism

- Ionizable lipids become positively charged.
- Negatively charged mRNA binds electrostatically.
- mRNA is trapped inside the forming lipid structure.

Why does IJM gives narrow size distribution?

- Uniform nucleation dominates over growth.
- No local concentration gradients.
- Particle size is fixed within the first milliseconds.

### Result

- Lipids become supersaturated.
- Lipid molecules self-assemble.
- mRNA is electrostatically encapsulated during particle formation.
- Now LNPs are formed inside IJM and now we need to analyze (using PAT) it and filter it.

### Key Concept :-

Mixing time is much shorter than nanoparticle assembly time, leading to uniform and reproducible LNPs.

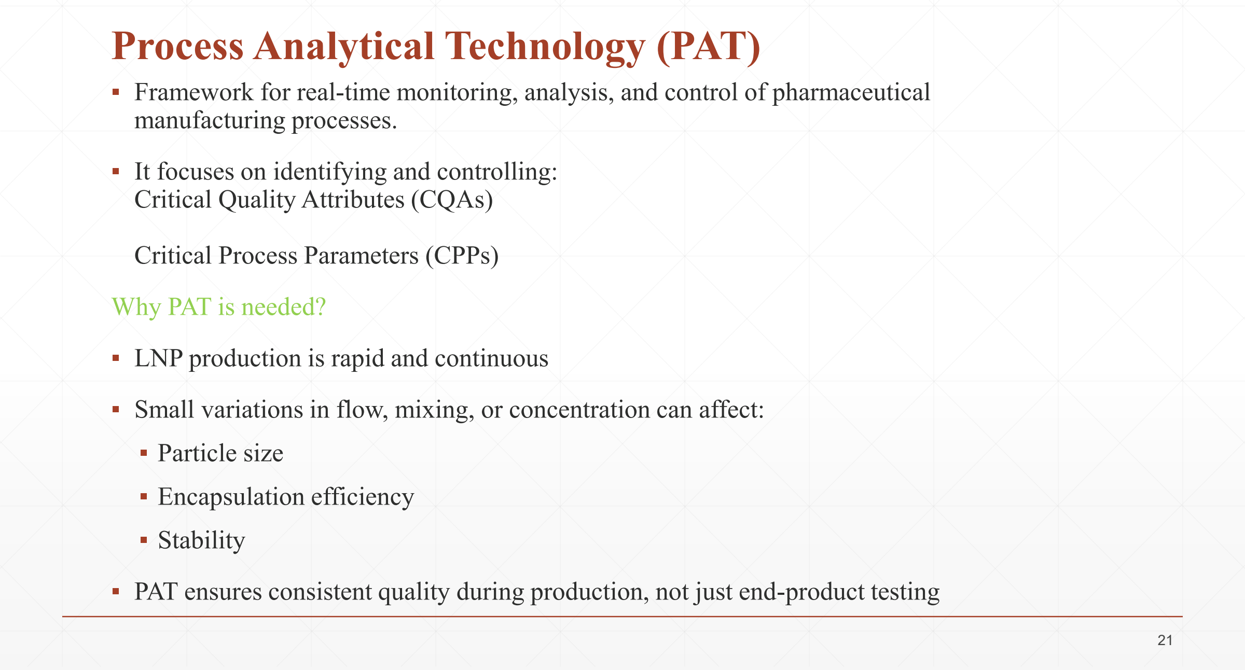
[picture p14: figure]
Process Analytical Technology (PAT); manufacturing processes.; Critical Quality Attributes (CQAs); Critical Process Parameters (CPPs); Why PAT is needed?; ▪ Particle size; ▪ Encapsulation efficiency; ▪ Stability

- Framework for real-time monitoring, analysis, and control of pharmaceutical
- It focuses on identifying and controlling:
- LNP production is rapid and continuous
- Small variations in flow, mixing, or concentration can affect:
- PAT ensures consistent quality during production, not just end-product testing

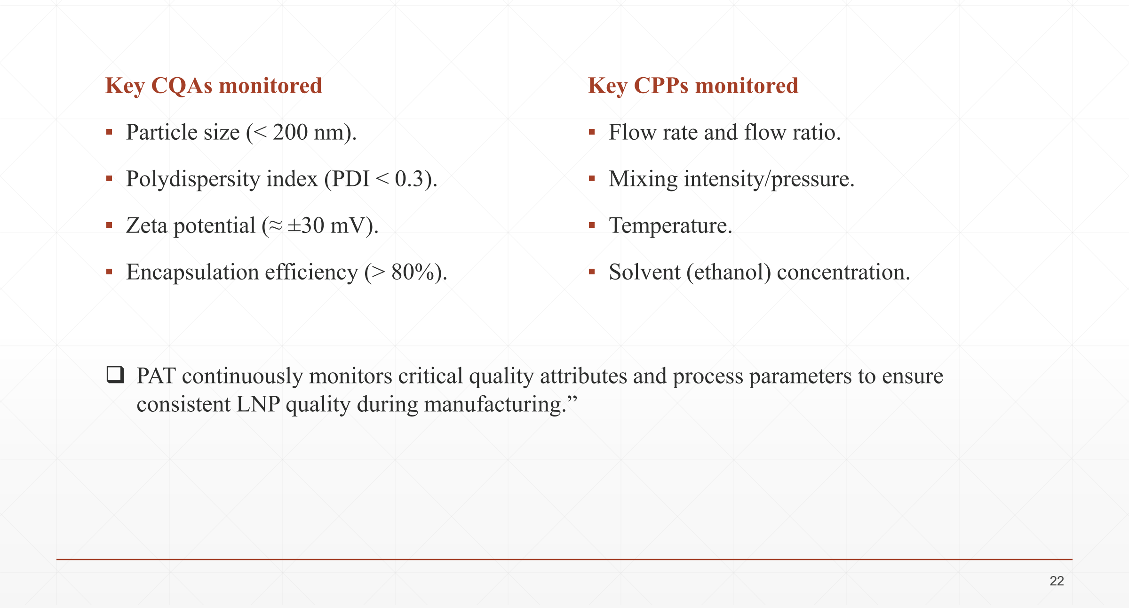
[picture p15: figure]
Key CQAs monitored; ▪ Particle size (< 200 nm).; ▪ Polydispersity index (PDI < 0.3).; ▪ Zeta potential (≈ ±30 mV).; ▪ Encapsulation efficiency (> 80%).; Key CPPs monitored; ▪ Flow rate and flow ratio.; ▪ Mixing intensity/pressure.; ▪ Temperature.; ▪ Solvent (ethanol) concentration.; consistent LNP quality during manufacturing.”

❑ PAT continuously monitors critical quality attributes and process parameters to ensure

### Quenching

Quenching by dilution is the immediate dilution of the freshly formed LNP suspension with an excess aqueous buffer.

- First , LNPs are formed.
- Now, quench buffer is added which results in sharp drop of ethanol concentration which reduces lipid solubility and mobility.
- Finally, particle growth ceases, preventing further fusion or aggregation, thereby locking in the final particle size and PDI.

Quenching by filtration is performed using Tangential Flow Filtration (TFF) or Membrane-based filtration to remove:

- Residual solvent (ethanol)
- Unencapsulated components

THIS IS THE FINAL STEP OF LNP MANUFACTURING.

# NxGen Mixing

- NxGen mixing is a controlled rapid-mixing technology.
- Based on controlled nanoprecipitation of lipids with nucleic acids.
- Mixing is done under high controlled flow conditions.
- Precise control over mixing time and flow profiles enables uniform particle formation and low PDI.
- Scale-up achieved via parallelization of microfluidic cartridges
- Single-use fluid paths reduce cross-contamination risk

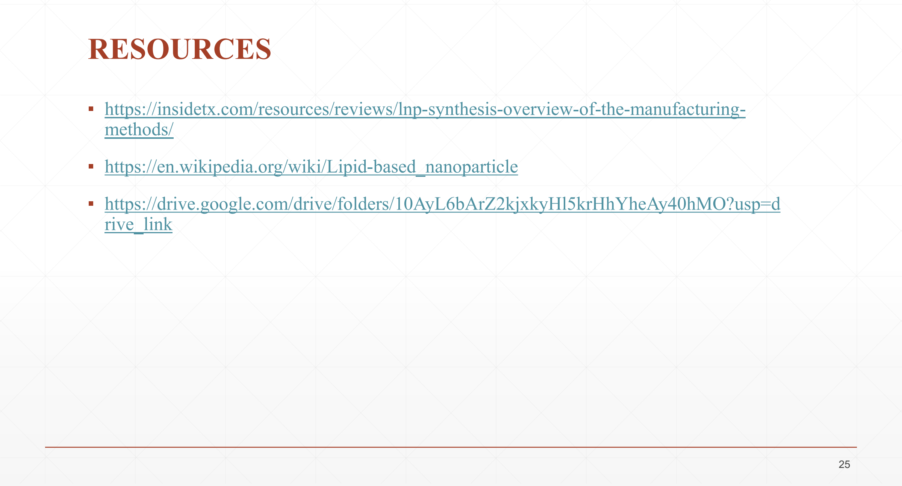
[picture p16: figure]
RESOURCES; ▪ https://insidetx.com/resources/reviews/lnp-synthesis-overview-of-the-manufacturing- methods/; ▪ https://en.wikipedia.org/wiki/Lipid-based_nanoparticle; ▪ https://drive.google.com/drive/folders/10AyL6bArZ2kjxkyHl5krHhYheAy40hMO?usp=d rive_link

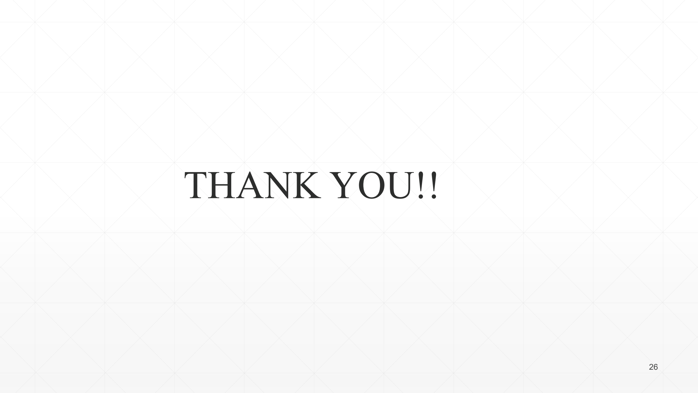
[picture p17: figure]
THANK YOU!!

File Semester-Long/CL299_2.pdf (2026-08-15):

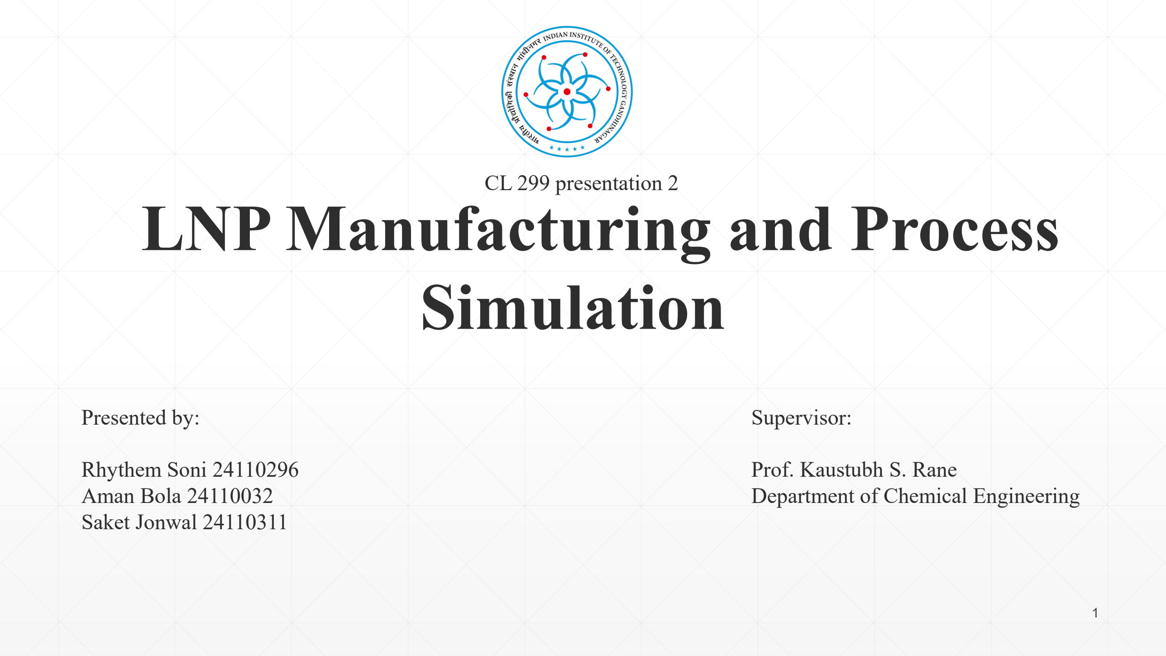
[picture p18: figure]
LNP Manufacturing and Process Simulation; CL 299 presentation 2; Supervisor:; Prof. Kaustubh S. Rane Department of Chemical Engineering; Presented by:; Rhythem Soni 24110296 Aman Bola 24110032 Saket Jonwal 24110311

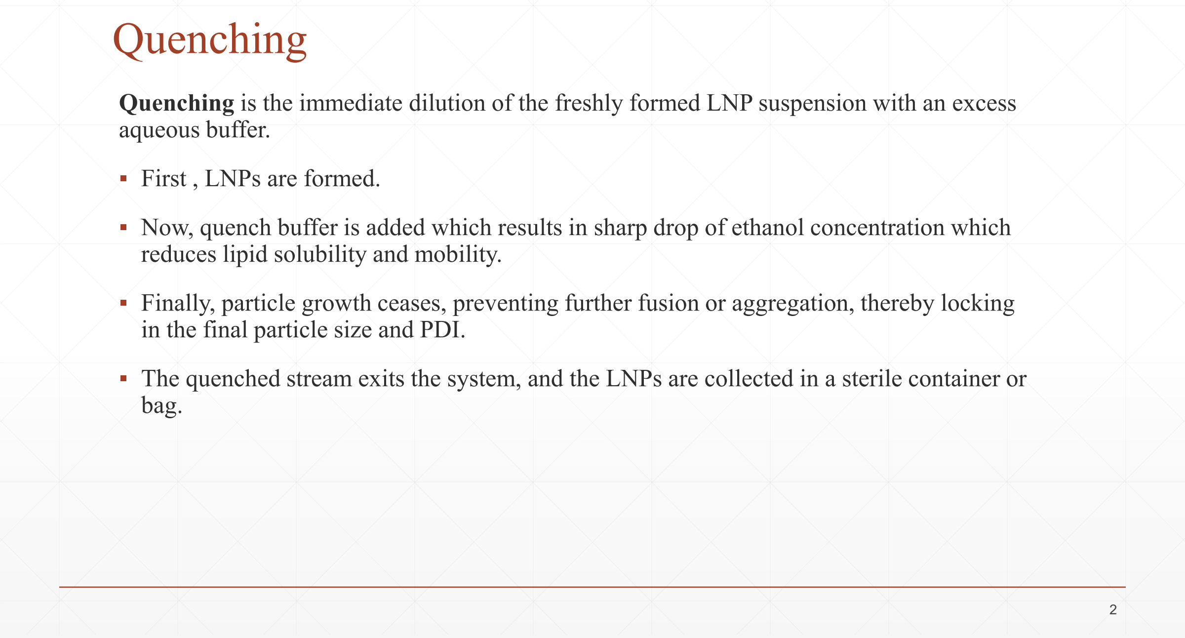
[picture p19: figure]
Quenching; aqueous buffer.; ▪ First , LNPs are formed.; reduces lipid solubility and mobility.; in the final particle size and PDI.; bag.

Quenching is the immediate dilution of the freshly formed LNP suspension with an excess

- Now, quench buffer is added which results in sharp drop of ethanol concentration which
- Finally, particle growth ceases, preventing further fusion or aggregation, thereby locking
- The quenched stream exits the system, and the LNPs are collected in a sterile container or

# Down-Stream Process

Downstream processing includes all steps carried out after product formation to purify, stabilize, ensure safety, and make it suitable for storage.

- After LNP formation, the suspension still contains residual ethanol, acidic buffer, free lipids, unencapsulated mRNA, incorrect concentration, and lacks sterility. Thus, while the LNP structure is correct, the surrounding environment and purity are unsuitable for use.
- Downstream processing ensures removal of ethanol and impurities, addition of buffer, and dosage adjustment, and a stable, sterile product for storage.
- To Achieve this we use Tangential Flow Filtration(TFF), Sterile Filtration ,Fill–Finish.

## Tangential Flow Filtration (TFF)

TFF simultaneously removes ethanol, enables buffer exchange (pH adjustment), and controls product concentration (Core purification & conditioning step).

- LNP suspension flows parallel to a membrane.
- Small molecules (ethanol, salts) pass through MWCO memberance in which driving force is TMP.
- LNPs are retained and recirculated.
- Fresh buffer is continuously added (diafiltration).

Source : https://upload.wikimedia.org/wikipedia/commons/thumb/3/32/Cross-flow.svg/500px-Cross-flow.svg.png (https://upload.wikimedia.org/wikipedia/commons/thumb/3/32/Cross-flow.svg/500px-Cross-flow.svg.png)

## Membrane MWCO

MWCO stands for Molecular Weight Cut-Off. It is the approximate molecular weight of the smallest molecule that the membrane will retain.

- MWCO is not an exact pore diameter. It is an operational definition, based on: Shape, Flexibility, Hydration of molecules.
- Ethanol, free lipid, M-RNA, salts, Buffer-molecule have approx. (MW :- /1KDa) which can easily pass through MWCO (100–250 KDa).

LNP = MW > 500KDa

- Molecules smaller than MWCO → pass through the membrane
- Molecules larger than MWCO → are retained

## Transmembrane Pressure (TMP)

- TMP is the pressure difference across the membrane. It is the driving force pushing small molecule to pass through the membrane.
- It Determines permeate flow rate, Controls how fast ethanol and buffer are removed.
- If TMP is too low then , Slow filtration and Long processing time.
- If TMP is too high then, Membrane fouling and LNP deformation or rupture.
- Cross-flow Rate(tangential velocity) is speed at which the LNP suspension flows parallel to the membrane.
- Diafiltration volume defines how many times the LNP solution is washed with fresh buffer during TFF, determining how completely small impurities are removed.

## Alternatives to TFF

| Alternative | | When Used | Limitations
| Dialysis | Lab Scale only | | Very Slow, Not scalable
Centrifugal purifications | | Small Batches | | Shear, Low scalablity
| SEC(Size Exlusions) | Analytical Purifications | | Not Industrial
| Precipitations | | Rare | High LNP loss

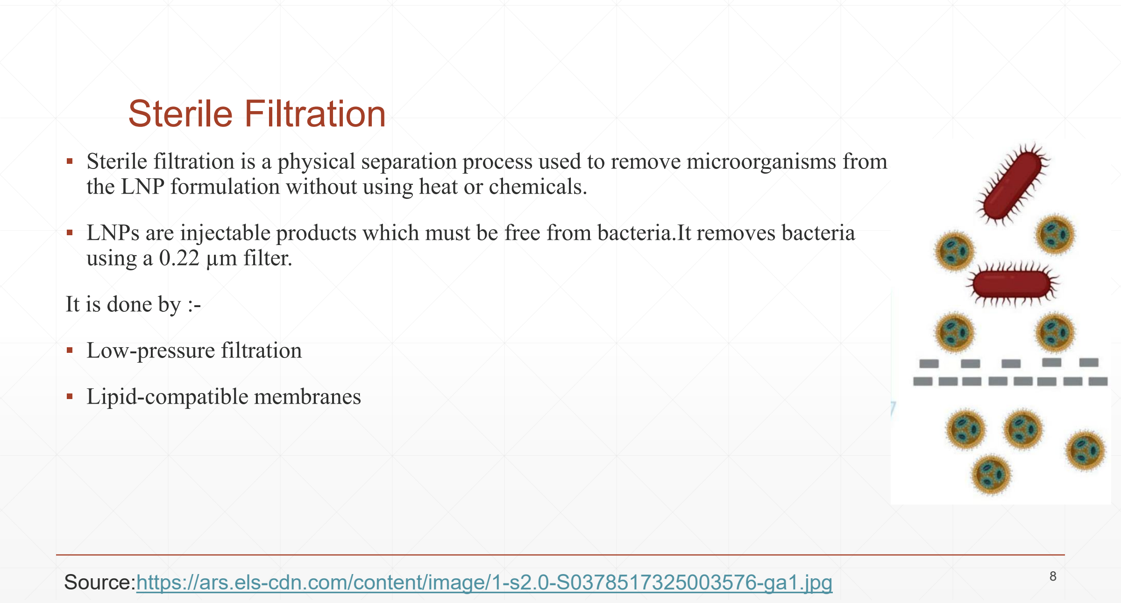
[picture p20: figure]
Sterile Filtration; using a 0.22 µm filter.; It is done by :-; ▪ Low-pressure filtration; ▪ Lipid-compatible membranes; Source:https://ars.els-cdn.com/content/image/1-s2.0-S0378517325003576-ga1.jpg

- Sterile filtration is a physical separation process used to remove microorganisms from the LNP formulation without using heat or chemicals.
- LNPs are injectable products which must be free from bacteria.It removes bacteria

Alternative Method | Why not used in LNP Formation
Heat Sterilization | Destroy M-RNA and melt lipid structure
Gamma irradiation | Cause RNA strands to break
Chemical sterilants | Leaves toxic residues
0.45 µm filtration | Not sufficient to ensure sterility
- Sterile filtration is the only practical sterilization method for mRNA-LNPs.

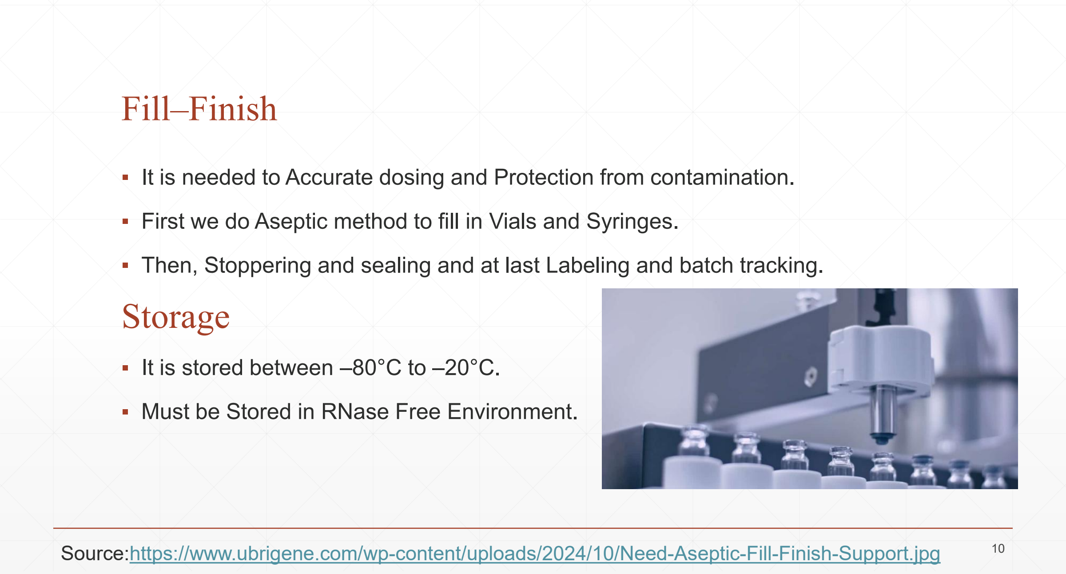
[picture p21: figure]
Fill–Finish; Storage; ▪ It is stored between –80°C to –20°C.; Source:https://www.ubrigene.com/wp-content/uploads/2024/10/Need-Aseptic-Fill-Finish-Support.jpg

- It is needed to Accurate dosing and Protection from contamination.
- First we do Aseptic method to fill in Vials and Syringes.
- Then, Stoppering and sealing and at last Labeling and batch tracking.
- Must be Stored in RNase Free Environment.

## mRNA Feed (Aqueous Phase)

- Single standed messenger RNA is dissolved in aqueous buffer.
- Buffer Concentration ≤ 25 mM.
- Typically 0.05 – 1 mg/mL
- Chosen based on desired final dose & encapsulation efficiency
- pH = 4.0 during mixing

## Buffer Systems and Lipid-RNA Relationships

- Allowed buffer bases:
- Tris, Bis-Tris, Triethanolamine (TEA)
- Allowed counter-anions:
- Chloride, Acetate, Lactate, Glycolate, etc.
- Buffer Concentration ≤ 25 mM
- Lipid : RNA (mass ratio):
- ~9 : 1 to ~20 : 1

## Lipid Feed (Organic Phase)

Component | Typical Role
Ionizable lipid | Electrostatic binding to mRNA
Phospholipid | Structural scaffold
Cholesterol | Membrane rigidity & packing
PEG-lipid | Size control & colloidal stability

Total lipid concentration is 10 mM

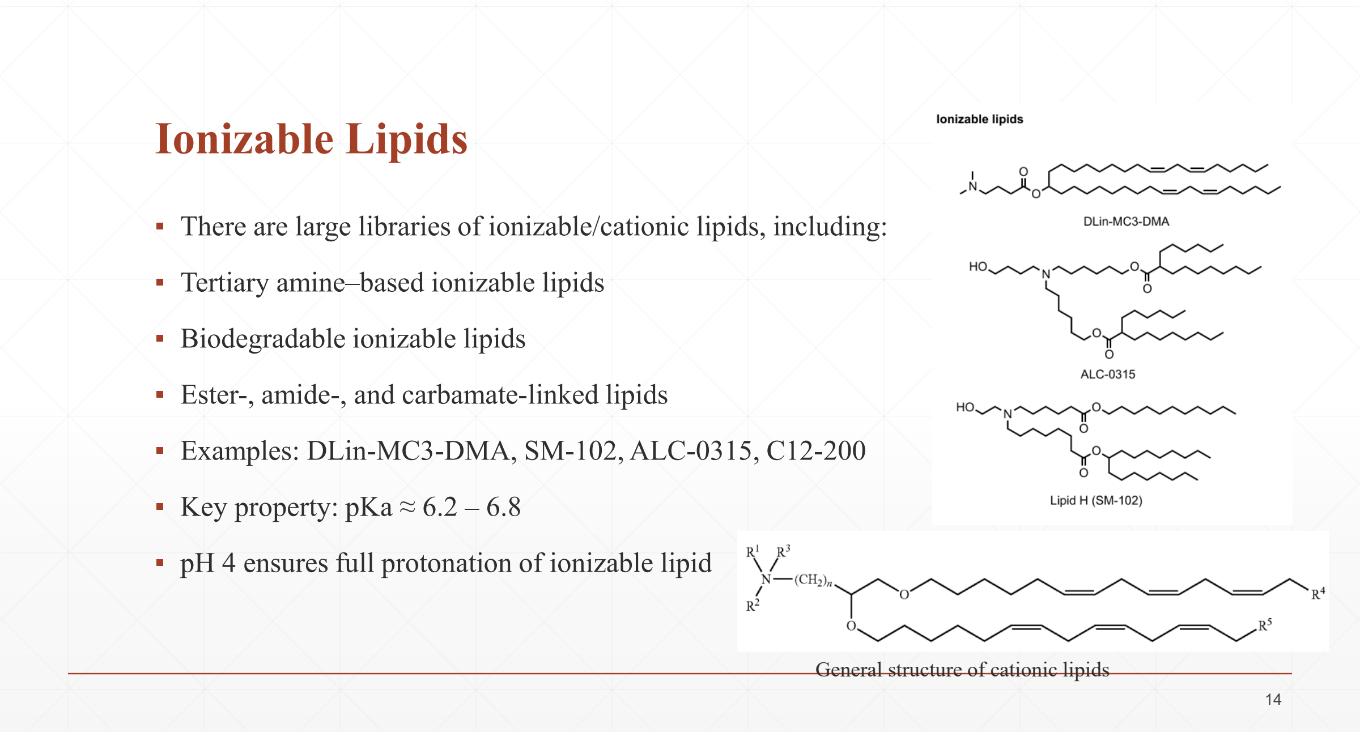
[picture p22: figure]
Ionizable Lipids; ▪ Tertiary amine–based ionizable lipids; ▪ Biodegradable ionizable lipids; ▪ Key property: pKa ≈ 6.2 – 6.8; General structure of cationic lipids

- There are large libraries of ionizable/cationic lipids, including:
- Ester-, amide-, and carbamate-linked lipids
- Examples: DLin-MC3-DMA, SM-102, ALC-0315, C12-200
- pH 4 ensures full protonation of ionizable lipid

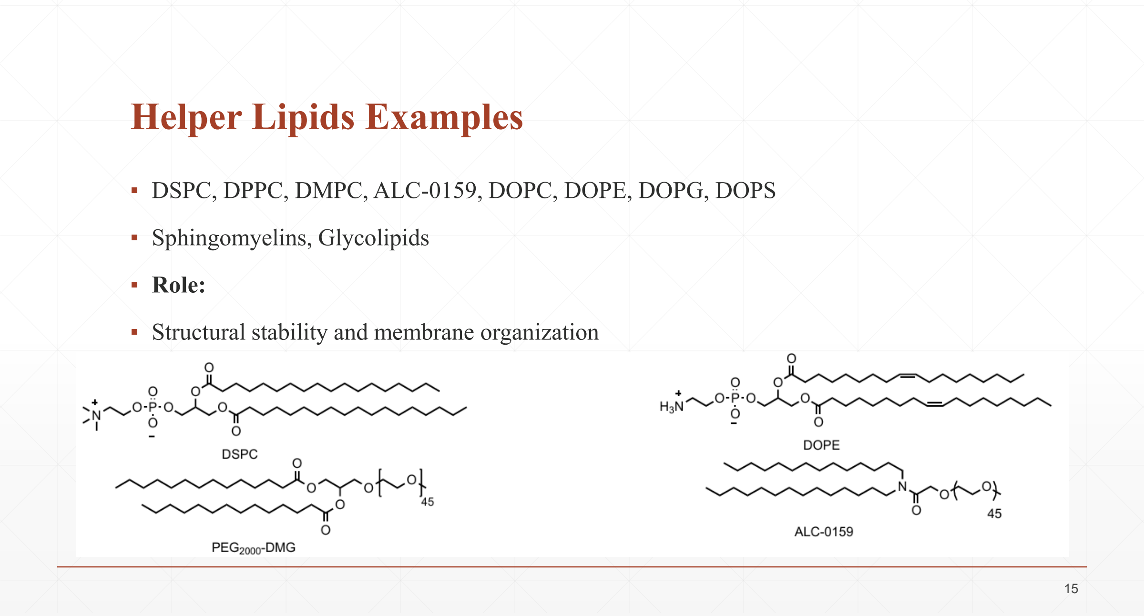
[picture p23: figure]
Helper Lipids Examples; ▪ Sphingomyelins, Glycolipids; ▪ Role:

- DSPC, DPPC, DMPC, ALC-0159, DOPC, DOPE, DOPG, DOPS
- Structural stability and membrane organization

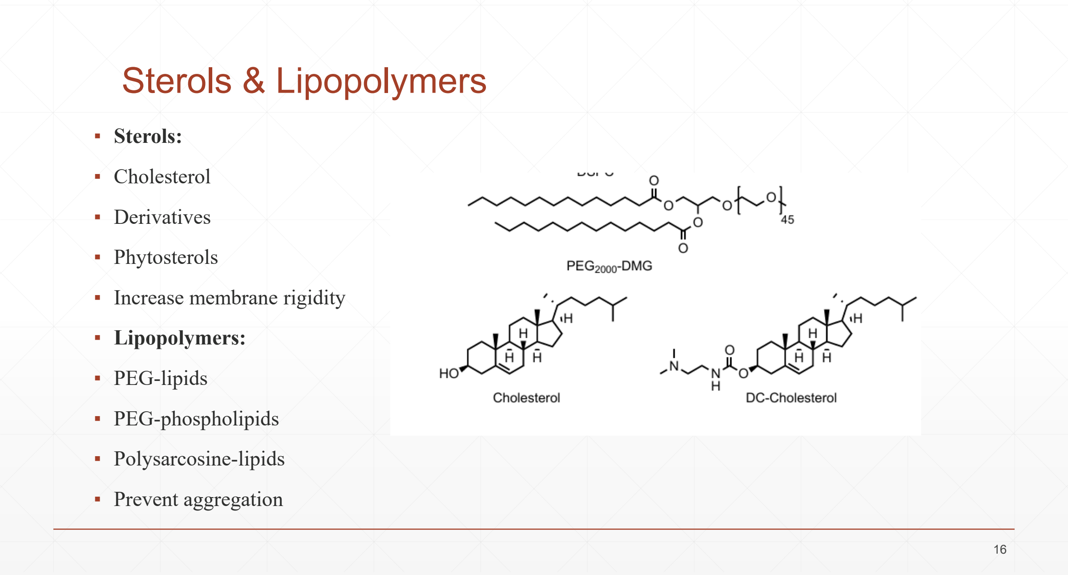
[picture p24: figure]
Sterols & Lipopolymers

- Sterols: ▪ Cholesterol ▪ Derivatives ▪ Phytosterols ▪ Increase membrane rigidity ▪ Lipopolymers: ▪ PEG-lipids ▪ PEG-phospholipids ▪ Polysarcosine-lipids ▪ Prevent aggregation

MMG: monomycoloyl glycerol

An example of composition from EPO patent. C12-200 LNPs were prepared by microfluidic mixing using the NanoAssemblr® Ignite microfluidic mixer system (Precision Nanosystems Inc., Vancouver, Canada), which uses a toroidal micromixer chip.

## Design Space

Component | Allowed Range (mol%) | Preferred Range
Ionizable lipid | 10 – 60 | 30 – 40
Helper lipid | 5 – 30 | 10 – 20
Sterol | 5 – 70 | 10 – 50
Lipopolymer | 0.5 – 50 | 1 – 5

Aqueous : Organic = 1:1 to 3:1, with 3:1 most commonly reported.

Obtaining structurally distinct LNPs often requires drastically changing the chemical composition.

N/P ratio (critical feed parameter); ▪ N/P ratio =; ▪ Values used: mRNA → N/P = 6; siRNA → N/P = 3; ▪ Directly affects:; ▪ particle formation; ▪ charge balance; ▪ encapsulation

(Number of protonatable nitrogens in ionizable lipid) / (Number of phosphate groups in RNA)

- Controls how much lipid is required per RNA

## Feed Variables Classified (Engineering View)

- Fixed / chosen upfront:
- Lipid identity
- Lipid molar ratio
- RNA concentration
- Buffer pH
- Tunable during operation:
- Flow rate
- Flow ratio
- Mixing intensity
- This classification is excellent for simulation justification.

Process Analytical Technology(PAT); monitor, and control pharmaceutical manufacturing processes in real time.; ▪ It is used for taking measurements directly during the process.; ▪ PAT data may measure chemical or physical aspects.

- FDA defines PAT as a system to analyse,

## Why Use PAT?

- Real-time and frequent measurements.
- Improved process understanding.
- Better process control and consistency.
- Enhanced safety.
- Ability to monitor difficult systems.
- Improved scale-up and technology transfer.

PAT Implementation; ▪ PAT integrates process understanding, real-time analysis, and control to ensure product quality.

Role of PAT in LNP Manufacturing; ▪ Particle size; ▪ Stability; ▪ Drug delivery performance; Critical Quality Attributes (CQAs); Critical Process Parameters (CPPs)

- Lipid nanoparticles are highly sensitive to process conditions
- Small process variations can significantly affect:
- PAT enables real-time monitoring and control during LNP production
- It focuses on identifying and controlling:

Some Analytical techniques used in PAT; ▪ Dynamic Light Scattering (DLS); ▪ Zeta Potential Analysis; ▪ X-ray Diffraction (XRD):; ▪ Mass Spectrometry (MS):; lipids.; ▪ Nuclear Magnetic Resonance (NMR):; LNP formulations.

This technique is used to measure particle size and size distribution in real-time.

This technique determines the surface charge of LNPs.

Analyzes the crystalline or amorphous nature of lipid components within LNPs.

Provides information on molecular weight and composition of lipids, especially ionizable

Provides detailed insights into lipid structure, composition, and molecular interactions in

▪ High-Performance Liquid Chromatography (HPLC):; ▪ Differential Scanning Calorimetry (DSC):

Quantifies lipid components and encapsulated payload (e.g., mRNA, siRNA).

Used to study the thermal behavior and phase transitions of lipids in LNP formulations.

# PAT Tools

- Multivariate tools for design, data acquisition, and analysis
- Process analyzers
- Process control tools
- Continuous improvement and knowledge management tools

An appropriate combination of some or all of these tools may be applicable to a single unit operation or to an entire manufacturing process and its quality assurance.

PAT Measurement Level; how useful it is for real-time control.; ▪ Four Analytical levels:; Offline: analysis after sample removal

- describe how closely an analytical method is connected to the manufacturing process and

At-line: analysis near the manufacturing line

In-line: sensor placed directly in the process stream

Online: automated sampling and analysis loop

- Process relevance and control capability increase from offline to online.

## Conclusion

- Process Analytical Technology (PAT) helps monitor and control pharmaceutical processes while manufacturing is happening.
- Instead of checking quality only at the end, PAT checks quality during the process, which improves reliability.
- Different measurement approaches (offline, at-line, inline, and online) allow PAT to be used flexibly in many processes.
- In lipid nanoparticle (LNP) manufacturing, PAT is very important because it helps control particle size, which affects product performance.
- Overall, PAT supports better process design, consistent quality, and modern manufacturing methods such as continuous processing.

# Resources:

- https://www.sciencedirect.com/science/article/abs/pii/S0378517325003576
- https://pubmed.ncbi.nlm.nih.gov/40139451/
- https://www.cytivalifesciences.com/en/us/insights/filtration-of-nucleic-acids-and-lnps-in-mrna-manufacture
- https://www.sharpservices.com/expert-content/beyond-lipids-the-science-of-lnp-manufacturing-and-fill-finish/
- https://advanced.onlinelibrary.wiley.com/doi/10.1002/adma.202419538
- https://www.researchgate.net/publication/361170223_Lipid_nanoparticle_formulations_for_optimal_RNA-based_topical_delivery_to_murine_airways (https://www.researchgate.net/publication/361170223_Lipid_nanoparticle_formulations_for_optimal_RNA-based_topical_delivery_to_murine_airways)
- https://data.epo.org/publication-server/rest/v1.2/patents/EP4442256NWA1/document.html
- https://patentimages.storage.googleapis.com/4b/d7/bf/442f9a59aba04c/US11191849.pdf
- https://patentimages.storage.googleapis.com/b9/d6/94/1da620d0bbb5a7/US20230414747A1.pdf

- https://pubs.acs.org/doi/full/10.1021/acs.accounts.1c00544
- https://www.tandfonline.com/doi/full/10.1517/17425247.2012.673278#d1e579
- https://www.nature.com/articles/s41578-021-00358-0
- https://www.tandfonline.com/doi/full/10.2147/IJN.S123062#d1e182
- https://link.springer.com/article/10.1007/s00216-010-3781-x#Sec8
- https://pubs.rsc.org/en/content/articlehtml/2010/ay/c0ay00257g
- https://pubs.acs.org/doi/full/10.1021/op400358b

THANK YOU!!!

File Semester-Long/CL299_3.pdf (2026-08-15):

LNP Manufacturing and Process Simulation; CL 299 presentation 3; Supervisor:; Prof. Kaustubh S. Rane Department of Chemical Engineering; Presented by:; Rhythem Soni 24110296 Aman Bola 24110032 Saket Jonwal 24110311

## PROCESS FLOW CHART –LAB SCALE

- We made the flow chart using draw.io software.
- In this flow chart we have covered mixing, TFF, ultra filtration, quenching, sterile filtration and cold storage.
- For aqueous phase we have used 25mM citrate buffer with target pH~4.
- For both the aqueous and organic phases, the temperature is between 20 – 25°C.
- we are using macrofluidic mixing as it is easier to operate at lab scale.

1. Microfluidic mixing. -Hydrodynamic focusing -Controlled laminar diffusion mixing; * Precise FRR and TFR control * Low PDI (<0.2) * High reproducibility * Suitable for 0.5–50 mL batches; Best for research optimization Precise size control; 2.Static T-Mixer (Syringe Pump-Based); * Two syringe pumps * T-junction connector * Controlled FRR (e.g., 3:1) * Total flow 2–12 mL/min; Low cost Easy to assemble Slightly higher size variability; 3.Rapid Injection / Vortex Mixing; * Inject lipid ethanol into stirring mRNA buffer * Magnetic stirrer or vortex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

## Alternatives of M101(macrofluidic mixture)

1. Amicon Ultra Centrifugal Filters (Most Common); * 100–300 kDa MWCO * Spin at 3,000–5,000 g * Volume: 1–50 mL * Used for: Ethanol removal Buffer exchange Concentration; Fast Widely used in labs Simple operation; 2.Dialysis Tubing System; * 100–300 kDa membrane * Buffer bath under stirring * 4–12 hour exchange; Very low cost No pump required Slow process Less control over TMP; 3.Stirred Cell Ultrafiltration (Pressure- Driven); * Nitrogen pressure system * Controlled membrane filtration * Better scalability than centrifuge filters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

## Alternatives for UF101 (Ethanol Removal & Buffer Exchange)

1. 0.22 µm Syringe Filter (Standard Lab Method); * PES / PVDF membrane * Manual sterile filtration * Used inside biosafety cabinet; Most common method Easy and affordable Suitable for small batches; 2.Vacuum Filtration Assembly; * 0.22 µm membrane * Vacuum pump * For 50–200 mL batches; Faster for larger volumes Controlled sterile handling; 3.Sterile Single-Use Assembly (Advanced Lab Setup); * Pre-sterilized tubing * Inline 0.22 µm filter * Closed transfer system; Mimics GMP process Reduces contamination risk Suitable for translational research

## Alternatives for F101 (Sterile Filtration)

## Catalogue Code

- We have used python as our coding language using the Google Colab for writing and executing code.
- We took reference of some patents and extracted the data from these patents using AI tools.
- We extracted information about various components of LNPs (particularly ionizable lipids, helper lipids, PEG-lipids and sterols).
- In data we have list of various compounds for each components of LNPs and their molecular weights.
- There are many compounds for which we have a range of molecular weight because they have number of units (n) which varies across mixture.
- Also, we have distribution of various categories.



PAT Measurement Level; how useful it is for real-time control.; ▪ Four Analytical levels:; Offline: analysis after sample removal.

- describe how closely an analytical method is connected to the manufacturing process and

At-line: analysis near the manufacturing line.

Online: automated sampling and analysis loop.

In-line: sensor placed directly in the process stream.

Process relevance and control capability increase from offline to Inline.

# Offline Analysis

- A sample is removed from process.
- Transported to a separate laboratory.
- Then analysed and results are obtained.
- Perform by manual sampling that can cause some sampling errors.
- Not real time monitoring.
- High accuracy and advance analysis.

Offline measurement is the traditional approach where quality is checked after sampling instead of during processing.

# At-line Analysis

- A sample is removed from the process.
- Analysed using equipment located near the production line.
- Faster analysis compared to offline laboratory testing.
- Performed by manual sampling and sampling errors may still occur.
- Not fully real-time monitoring but provides quicker feedback.
- Allows rapid process monitoring and adjustment.

At-line measurement is an intermediate approach where analysis is done close to the process, providing faster results than offline analysis but still requiring sample removal.

# Online Analysis

- Sample is automatically taken from the process using a bypass system.
- Analytical equipment is connected directly to the production line.
- Sample may be conditioned before analysis (e.g., dilution or temperature control).
- Provides near real-time monitoring.
- Reduces manual sampling errors.
- Allows continuous process monitoring and faster feedback.

The disadvantages of online analysis are the higher capital costs that arise from the automation and the requirements for robustness of the analytical equipment.

# In-line Analysis

- Measurement is performed directly inside the process.
- Analytical sensor is integrated into the production line.
- No sample removal is required.
- Provides continuous and real-time monitoring.
- Enables immediate detection of process changes.
- Supports automatic process control and optimization.

Inline measurement is an in-situ approach where analysis occurs directly within the process stream, allowing real-time monitoring and control without manual sampling.

Level | Sample removal | Real-time | Control capability
Offline | Yes | No | Low
At-line | Yes | Limited | Medium
Online | Automated | Near real-time | High
Inline | No | Real-time | Highest

CLASSIFICATION OF TECHNIQUES; ▪ Near-infrared spectroscopy (NIR) Measures molecular vibrations.; ▪ Infrared spectroscopy; ▪ Nuclear magnetic resonance (NMR); magnetic properties of atomic nuclei. Offline and online.; ▪ Raman spectroscopy; scattering from molecules online and inline.

Used for real-time process monitoring as online and inline.

This technique is used to identify chemical bonds and molecular structures
Used for real-time process monitoring as online and inline(major).

This technique is used to determine molecular structure and chemical composition using

This technique is used to analyze molecular structure and composition by measuring light

- Dynamic light scattering (DLS)
This technique is used to measure particle size and size distribution in real-time.
Inline.
- Fluorescence
This technique is used to detect specific molecules and monitor nanoparticle formation or payload distribution
offline
- Surface plasmon resonance (SPR)
Surface plasmon resonance is an optical sensing technique that measures changes in refractive index at a metal surface to detect molecular interaction.
Inline.
- reflective interference spectroscopy (RIF)
measures interference patterns of reflected light to detect changes in surface thickness or refractive index.
Inline.

▪ Mass spectrometry (MS); online.; ▪ Electrochemical sensors measure the chemical properties. Inline.; ▪ NIR Turbidity; Inline.; ▪ Capacitance: Inline.; ▪ IR Absorption; Online and inline.

provides information about the molecular weight and composition of lipids

uses Near-Infrared (NIR) light to determine how cloudy or particle-rich a liquid is.

Infrared (IR) absorption occurs when molecules absorb infrared radiation, causing changes in vibrational and rotational energy levels.

▪ (Bio)chemical Analysers; offline.; ▪ Calorimetry; online.; ▪ Confocal Spectroscopy (CICS) used for high-resolution nanoparticle characterization offline.; ▪ Consistent cryo-electron microscopy (Cryo-EM); resolution. offline

used to measure chemical or biological components

measuring heat transfer during physical or chemical processes

This technique is used to visualize nanoparticle structure and morphology at very high

▪ Small-angle X-ray scattering (SAXS).; using X-ray scattering. offline; ▪ Computational Fluid Dynamics (CFD) uses mathematical modeling and simulations. Offline.; ▪ Zeta potential Analysis; Inline and at-line.

This technique is used to analyze nanoscale structure and internal organization of particles

This technique determines the surface charge.

- Optical Microscopy and Electron Microscopy
helping to identify any issues like agglomeration or structural defects. Offline.
- Differential Scanning Calorimetry (DSC)
(Thermal analysis, not real-time).
Offline.
- X-ray Diffraction (XRD)
This technique is used to determine crystal structure and phase composition by analyzing X-ray diffraction patterns.
Offline.
- High-Performance Liquid Chromatography (HPLC)
On-line possible via auto-samplers for drug loading, encapsulation efficiency, or degradation monitoring.
- Fourier Transform Infrared Spectroscopy (FTIR)
Can be on-line with ATR-FTIR probes, but typically offline unless specialized probe systems are used.

- UV spectroscopy
used to measure chemical changes and molecular concentration.
- Ultrasonic crystallization monitoring (UCM)
uses ultrasonic waves to monitor crystallization processes by detecting particle formation and phase changes
- Photometric stereo imaging
Photometric stereo imaging reconstructs surface shape by analyzing images taken under different lighting angles.
At-line and online.
- FBRM (Focused Beam Reflectance Measurement)
this technique is used to monitor particle size and count in real time
- PVM (Particle Vision and Measurement)
captures real-time images of particles inside a process to monitor particle shape, size, and behavior.
Inline.

## Resources

- https://docs.google.com/presentation/d/18YQe9UQSGdCi0CvTygbpCGwfLPhk4ogJ/edit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 (https://docs.google.com/presentation/d/18YQe9UQSGdCi0CvTygbpCGwfLPhk4ogJ/edit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)
- https://drive.google.com/file/d/1qwG77msmF2oO8doUGwgtkrXdz0KD0xtk/view?usp=sharing
- https://drive.google.com/file/d/1qwG77msmF2oO8doUGwgtkrXdz0KD0xtk/view?usp=sharing

Patents & Patent Applications:

- D. G. Anderson et al., “Lipid nanoparticles for nucleic acid delivery,” U.S. Patent 9,512,092, Dec. 6, 2016.
- M. J. Hope et al., "Lipid nanoparticle formulations," W.O. Patent 2018/081480 A1, May 3, 2018.
- S. M. Ansell et al., "Methods of preparing lipid nanoparticles," W.O. Patent 2020/160397 A1, Aug. 6, 2020.
- S. G. Hoge et al., "Compositions and methods for delivering messenger RNA," U.S. Patent 11,191,849 B2, Dec. 7, 2021.

- D. G. Anderson et al., “Lipid-like compounds and methods of use,” U.S. Patent 9,993,512, Jun. 12, 2018.
- H. Dong et al., “Biodegradable lipid nanoparticles for nucleic acid delivery,” U.S. Patent 10,221,127, Mar. 5, 2019.
- K. Karikó et al., “Lipid nanoparticle compositions for RNA delivery,” U.S. Patent 10,933,127, Mar. 2, 2021.
- K. Karikó et al., “RNA-containing lipid nanoparticles and uses thereof,” U.S. Patent 10,702,600, Jul. 7, 2020.
- K. R. Love et al., “Lipid nanoparticles for nucleic acid delivery,” U.S. Patent 10,221,127, Mar. 5, 2019.
- M. J. Hope et al., “Cationic lipids for nucleic acid delivery,” U.S. Patent 7,531,490, May 12, 2009.
- P. R. Cullis, M. J. Hope, and T. D. Madden, “Lipid nanoparticle formulations for delivery of nucleic acids,” U.S. Patent 8,058,069, Nov. 15, 2011
- S. M. Ansell et al., "Methods for preparation of lipid-encapsulated therapeutic agents," U.S. Patent Application 2022/0001029 A1, Jan. 6, 2022.
- S. A. Stanton et al., "Lipid nanoparticle compositions and methods of formulating the same," E.P. Patent Application 4 046 629 A1, Aug. 24, 2022.
- S. M. Ansell and X. Du, "Lipids and lipid nanoparticle formulations for delivery of nucleic acids," U.S. Patent 11,648,324 B2, May 16, 2023.

- P. Samayoa, N. Silver, G. Feinstein, and M. LeBlanc, "Lipid nanoparticle compositions and uses thereof," W.O. Patent 2023/239756 A1, Dec. 14, 2023.
- Acuitas Therapeutics, Inc., "Lipid nanoparticle compositions," E.P. Patent Application 4 442 256 A1, 2024.
- L. Dagge, K. Harr, M. Paul, and G. Schnedl,
“Classification of process analysis: Offline – Atline – Online – Inline,”
Cement International, vol. 7, no. 5, pp. 2–8, 2009.
- A. de Juan and R. R. de Oliveira,
“Hyperspectral image and chemometrics. A step beyond classical spectroscopic PAT tools,” Analytical and Bioanalytical Chemistry, vol. 418, pp. 23–34, 2025,
doi: 10.1007/s00216-025-06154-x.
- G. Gerzon, Y. Sheng, and M. Kirkitadze,
“Process analytical technologies – Advances in bioprocess integration and future perspectives,”
Journal of Pharmaceutical and Biomedical Analysis, vol. 207, 114379, 2021,
doi: 10.1016/j.jpba.2021.114379.
- P. L. Ahl, “Microfluidic and turbulent mixing for mRNA LNP vaccines,” Pharmaceutics, vol. 17, no. 9, Art. no. 1148, 2025, doi: 10.3390/pharmaceutics17091148.

THANK YOU!!!

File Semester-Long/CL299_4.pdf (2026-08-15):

LNP Manufacturing and Process Simulation; CL 299 presentation 4; Supervisor:; Prof. Kaustubh S. Rane Department of Chemical Engineering; Presented by:; Rhythem Soni 24110296 Aman Bola 24110032 Saket Jonwal 24110311

## Key Process Parameters

Parameter | Value
Flow rate ratio (aqueous : organic) | 3 : 1
Total mixer flow | 12 mL/min
Ethanol fraction after mixing | 25 %
Parameter | Value
Dilution buffer flow | 36 mL/min
Total flow after dilution | 48 mL/min
Ethanol concentration | 6.25 %

Mixer Conditions

Dilution Step

Parameter | Value
Membrane MWCO | 100 kDa
TMP | 1 bar
Crossflow rate | 30–100 mL/min
Concentration factor | 6×

TFF Operation

Material Balance Key Streams; Stream; Flow; Organic lipid solution; 3 mL/min; Aqueous mRNA solution; 9 mL/min; Dilution buffer; 36 mL/min; Feed Streams; Total Feed to TFF: 48 mL/min Final Product Flow Rate: 7.5 mL/min Composition: • Lipids = 30 mg/min • mRNA = 4.5 mg/min • Buffer salts = 102 mg/min; Overall Balance: Input = 48 mL/min Output = 48 mL/min

## The Nanoparticle Structure (Primary Lipids)

Ionizable Lipids

- Definition: Lipids that change their electrical charge based on the surrounding pH (acidic vs. neutral).
- Use: Bind and encapsulate the negatively charged RNA payload, and later help release it inside the target cell.

Helper Phospholipids

- Definition: Structural lipids that form the foundation of standard cell membranes.
- Use: Provide structural integrity to the LNP and help the nanoparticle fuse with the target cell's membrane.

Sterols; nanoparticle core.; PEG Lipids; from the immune system.

- Definition: Rigid, ring-structured lipid molecules (e.g., cholesterol).
- Use: Fill gaps between other lipids to regulate the structural fluidity and stability of the
- Definition: Lipids attached to polyethylene glycol (PEG) polymer chains.
- Use: Coat the LNP surface to prevent particles from clumping together and hide them

Manufacturing & Processing Agents; Organic Solvents; hydrophobic materials.; initial nanoparticle formation process.; Buffer Acids & Salts; charge to efficiently bind the RNA.

- Definition: Carbon-based liquids (e.g., ethanol, methanol) capable of dissolving
- Use: Dissolve the lipids so they can be mixed with the water-soluble RNA during the
- Definition: Chemical systems designed to maintain a specific, constant pH in a solution.
- Use: Control the pH during mixing to ensure ionizable lipids carry the necessary positive

Storage & Protection Excipients; Cryoprotectants; structures at freezing temperatures.; during deep-freeze storage.; Antioxidants; of the formulation.

- Definition: Specific sugars or polyols (e.g., sucrose, trehalose) that protect physical
- Use: Prevent ice crystals from physically piercing and destroying the fragile lipid spheres
- Definition: Compounds that inhibit oxidation reactions.
- Use: Protect lipids and RNA from oxidative degradation, extending the overall shelf life

Chelating Agents; enzymes that destroy RNA.

- Definition: Molecules (e.g., EDTA) that bind tightly to free, reactive metal ions.
- Use: Trap trace metals that would otherwise catalyze drug degradation or activate

Final Formulation & Delivery Excipients; Surfactants; liquids.; manufacturing tubing.; Salts

- Definition: Surface-active agents (e.g., Polysorbate 20) that lower the surface tension of
- Use: Prevent the nanoparticles from sticking to the walls of glass vials, syringes, and
- Definition: Standard ionic compounds (e.g., Sodium Chloride).
- Use: Ensure the final liquid suspension matches the salt concentration of human blood to prevent cell damage and pain upon injection.

Stabilizers; settling or aggregating over time.

- Definition: Viscosity-modifying or structure-supporting agents (e.g., Glycerol).
- Use: Keep the nanoparticle suspension evenly mixed and prevent the particles from

Level | Sample removal | Real-time | Control capability
Offline | Yes | No | Low
At-line | Yes | Limited | Medium
Online | Automated | Near real-time | High
Inline | No | Real-time | Highest

## INLINE

- Near-infrared Spectroscopy (NIR)
this technique measure molecular vibrations→ a fiber-optic NIR probe is installed directly inside the tablet coating equipment, measuring spectra continuously during coating.
- Infrared Spectroscopy
used to identify chemical bonding →For bioreactors.
- Nuclear Magnetic resonance (NMR)
used to determine molecular structures→flow water-proton NMR can be used as an inline PAT tool in continuous biomanufacturing to monitor protein concentration and aggregation in real time using water-proton relaxation signals.
- Raman Spectroscopy
analyse molecular structure and composition by measuring light scattering from molecules. → powder blending process
- Dynamic Light Scattering (DLS)
used to measure particle size.
- Reflective Interference Spectroscopy
measures interference patterns of reflected light to detect changes in surface thickness or refractive index
and used as an optical biosensor to detect biomolecular binding by measuring changes in the interference of reflected light from a sensor surface

- Surface Plasmon resonance (SPR)
Surface plasmon resonance is an optical sensing technique that measures changes in refractive index at a metal surface to detect molecular interaction
- Mass Spectroscopy
provides information about the molecular weight →to monitor and characterize monoclonal antibodies in real time during purification.
- NIR Turbidity
uses Near-Infrared (NIR) light to determine how cloudy or particle-rich a liquid is.
- IR Absorption
Infrared (IR) absorption occurs when molecules absorb infrared radiation, causing changes in vibrational and rotational energy levels.
- Zeta potential Analysis
This technique determines the surface charge
- PVM (Particle Vision and Measurement)
captures real-time images of particles inside a process to monitor particle shape, size, and behavior.

to measure some parameters-; 1. pH sensors 2. Flow meters 3. Temperature probs 4. Conductivity sensors

Now in addition to all the techniques using inline classification, we have some tools that are used

## ONLINE

- NIR → online NIR spectroscopy with an adaptive model-updating strategy to monitor industrial processes in real time as a PAT tool.
- Infrared Spectroscopy & Mass Spectroscopy
methanol electro-oxidation on a Pt catalyst using in-situ IR spectroscopy and online mass spectrometry to monitor reaction intermediates and products during the reaction.
- NMR →flow-NMR as an online PAT tool to monitor chemical reactions in real time by measuring reactant and product concentrations directly in the flowing reaction mixture.
- Raman Spectroscopy
- IR absorption→IR absorption at 5.85 μm to detect oxidation in lubricating oil and proposes a compact sensor for online oil condition monitoring.
- High-Performance Liquid Chromatography (HPLC)
On-line possible via auto-samplers for drug loading, encapsulation efficiency, or degradation monitoring.

in yeast fermentation in real time.; ▪ Photometric stereo imaging; lighting angles.

- Fourier Transform Infrared Spectroscopy (FTIR)
online FT-IR spectroscopy as a PAT tool to monitor glucose consumption and ethanol production

Photometric stereo imaging reconstructs surface shape by analyzing images taken under different

## ATLINE

- Zeta potential analysis
- Fluorescence →Atomic fluorescence spectrometry is a specific type of fluorescence technique used to detect trace metals by measuring fluorescence from atoms.
- NIR → During fermentation, samples were taken from the bioreactor and analyzed using Near-Infrared Spectroscopy (NIR) to estimate glucose and biomass using PLS models.
- Liquid Chromatography → at-line RP-UPLC (liquid chromatography) to monitor protein concentration during microfiltration.
- Raman Spectroscopy → portable Raman spectroscopy used as an at-line PAT tool to characterize carbon nanomaterials and monitor their structural quality during manufacturing.

18

OFFLINE; ▪ NMR , FTIR; ▪ Fluorescence; ▪ (Bio)chemical Analysers; ▪ Confocal Spectroscopy (CICS) used for high-resolution nanoparticle characterization. offline.; ▪ Consistent cryo-electron microscopy (Cryo-EM); resolution. offline

used to measure chemical or biological components

This technique is used to visualize nanoparticle structure and morphology at very high

- Small-angle X-ray scattering (SAXS)
This technique is used to analyze nanoscale structure and internal organization of particles using X-ray scattering.
offline
- Optical Microscopy and Electron Microscopy
helping to identify any issues like agglomeration or structural defects. Offline.
- Differential Scanning Calorimetry (DSC)
(Thermal analysis, not real-time).
Offline.
- X-ray Diffraction (XRD)
This technique is used to determine crystal structure and phase composition by analyzing X-ray diffraction patterns.
Offline.
- NIR & Raman Spectroscopy
off-line NIR was used to correlate ribbon density with chemical absorption spectra, while off-line Raman spectroscopy was used to predict tablet hardness by analyzing surface smoothness and density.

## Classification of techniques

Techniques | Offline | | Atline | Online | Inline
Near-infrared Spectroscopy (NIR) | | ✓ | ✓ | ✓ | ✓
Infrared spectroscopy | | | | ✓ | ✓
Nuclear magnetic resonance (NMR) Raman spectroscopy | | ✓ ✓ | ✓ | ✓ ✓ | ✓ ✓
Dynamic light scattering (DLS) | | | | | ✓
Fluorescence | | ✓ | ✓
Surface plasmon resonance (SPR) | | | | | ✓

Techniques | Offline | Atline | Online | Inline
Reflective Interference Spectroscopy | | | | ✓
Mass spectrometry (MS) | | | ✓ | ✓
NIR Turbidity | | | | ✓
IR Absorption | | | ✓ | ✓
Consistent cryo-electron microscopy (Cryo-EM) | ✓
Confocal Spectroscopy (CICS) | ✓
Small-angle X-ray scattering (SAXS). | ✓
Zeta potential Analysis | | ✓ | | ✓

Techniques | Offline | | Atline | Online | Inline
X-ray Diffraction (XRD) | | ✓
High-Performance Liquid Chromatography (HPLC) | | | | ✓
Fourier Transform Infrared Spectroscopy (FTIR) | ✓ | | | ✓
PVM (Particle Vision and Measurement) | | | | | ✓
Photometric stereo imaging | | | | ✓

Techniques | Offline | Atline | Online | Inline
Differential Scanning Calorimetry (DSC) | ✓
Liquid Chromatography | | ✓
Optical Microscopy and Electron Microscopy | ✓
pH sensors | | | | ✓
Flow meters | | | | ✓
Temperature probs | | | | ✓
Conductivity sensors | | | | ✓

## Resources

- K. Knop and P. Kleinebudde, “PAT-tools for process control in pharmaceutical film coating applications,” International Journal of Pharmaceutics, vol. 457, no. 2, pp. 527–536, 2013, doi: 10.1016/j.ijpharm.2013.01.062.
- https://drive.google.com/file/d/1qwG77msmF2oO8doUGwgtkrXdz0KD0xtk/view?usp=drive_link
- M. B. Taraban, K. T. Briggs, P. Merkel, and Y. B. Yu, “Flow water proton NMR: In-line process analytical technology for continuous biomanufacturing,” Analytical Chemistry, vol. 91, no. 21, pp. 13538–13546, 2019, doi: 10.1021/acs.analchem.9b02622.
- T. R. M. De Beer, C. Bodson, B. Dejaegher, B. Walczak, P. Vercruysse, A. Burggraeve, A. Lemos, L. Delattre, Y. Vander Heyden, J. P. Remon, C. Vervaet, and W. R. G. Baeyens, “Raman spectroscopy as a process analytical technology (PAT) tool for the in-line monitoring and understanding of a powder blending process,” Journal of Pharmaceutical and Biomedical Analysis, vol. 48, no. 3, pp. 772–779, 2008, doi: 10.1016/j.jpba.2008.07.023.
- K. | M. Prentice, A. Wallace, and C. Eakin, | “Inline Protein A Mass Spectrometry for Characterization
of Monoclonal Antibodies,” Analytical Chemistry, vol. 87, | no. 5, pp. 2790–2796, 2015, doi:
10.1021/ac504502e.

- K. He, H. Cheng, W. Du, and F. Qian, “Online updating of NIR model and its industrial application via adaptive wavelength selection and local regression strategy,” Chemometrics and Intelligent Laboratory Systems, vol. 134, pp. 79–88, 2014, doi: 10.1016/j.chemolab.2014.03.007.
- R. Reichert, J. Schnaidt, Z. Jusys, and R. J. Behm, “The influence of reactive side products on the electrooxidation of methanol—A combined in situ infrared spectroscopy and online mass spectrometry study,” Physical Chemistry Chemical Physics, vol. 16, pp. 13780–13799, 2014, doi: 10.1039/C4CP01229A.
- D. A. Foley, E. Bez, A. Codina, K. L. Colson, M. Fey, R. Krull, D. Piroli, M. T. Zell, and B. L. Marquez, “NMR flow tube for online NMR reaction monitoring,” Analytical Chemistry, vol. 86, no. 24, pp. 12008–12013, 2014, doi: 10.1021/ac502300q.
- A. Agoston, C. Otsch, J. Zhuravleva and B. Jakoby, "An IR-absorption sensor system for the determination of engine oil deterioration [automotive applications]," SENSORS, 2004 IEEE, Vienna, Austria, 2004, pp. 463-466 vol.1, doi: 10.1109/ICSENS.2004.1426200. keywords: {Sensor systems;Engines;Petroleum;Automotive applications;Electromagnetic wave absorption;Infrared spectra;Spectroscopy;Laboratories;Oxidation;Condition monitoring},
- E. L. Veale, J. Irudayaraj, and A. Demirci, “An on-line approach to monitor ethanol fermentation using FTIR spectroscopy,” Biotechnology Progress, vol. 23, no. 2, pp. 494–500, 2007, doi: 10.1021/bp060306v.

- N. K. Brahma, W. T. Corns, P. B. Stockwell, L. Ebdon, and E. H. Evans, “At-line determination of mercury | in process
streams using atomic | fluorescence spectrometry,” Journal of Analytical Atomic Spectrometry, vol. 12, pp. 611–616, 1997,
doi: 10.1039/A608550D.
- C. Hakemeyer, U. Strauss, S. Werz, G. E. Jose, F. Folque, and J. C. Menezes, | “At-line NIR spectroscopy as effective
PAT monitoring technique in Mab cultivations during process development and manufacturing,” | Talanta, vol. 90, pp. 12–
21, 2012, doi: 10.1016/j.talanta.2011.12.042.
- D. S. Watson, K. R. Kerchner, S. S. Gant, J. W. Pedersen, J. B. Hamburger, A. D. Ortigosa, and T. I. Potgieter, “Atline process analytical technology (PAT) for more efficient scale up of biopharmaceutical microfiltration unit operations,” Biotechnology Progress, vol. 32, no. 1, pp. 108–115, 2016, doi: 10.1002/btpr.2193.
- D. Yang and K. Frano, “Portable Raman spectroscopy for at-line characterization of carbon nanomaterials,” Spectroscopy Online, Jun. 1, 2018. [Online]. Available: https://www.spectroscopyonline.com/view/portable-raman-spectroscopy-linecharacterization (https://www.spectroscopyonline.com/view/portable-raman-spectroscopy-line-characterization-carbon-nanomaterials)- (https://www.spectroscopyonline.com/view/portable-raman-spectroscopy-line-characterization-carbon-nanomaterials)carbon (https://www.spectroscopyonline.com/view/portable-raman-spectroscopy-line-characterization-carbon-nanomaterials)- (https://www.spectroscopyonline.com/view/portable-raman-spectroscopy-line-characterization-carbon-nanomaterials)nanomaterials (https://www.spectroscopyonline.com/view/portable-raman-spectroscopy-line-characterization-carbon-nanomaterials)
- M. A. P. McAuliffe, G. E. O’Mahony, C. A. Blackshields, J. A. Collins, D. P. Egan, L. Kiernan, E. O’Neill, S. Lenihan,
G. M. Walker, and A. M. Crean, “The use of PAT and off-line methods for monitoring of roller compacted ribbon and granule properties with a view to continuous processing,” Organic Process Research & Development, vol. 19, no. 1, pp. 158–166, 2015, doi: 10.1021/op5000013.
- R. van Reis and A. L. Zydney, “Bioprocess membrane technology,” Journal of Membrane Science, vol. 297, pp. 16–50, 2007.
- R. H. Perry and D. W. Green, Perry’s Chemical Engineers’ Handbook, 8th ed. New York, NY, USA: McGraw-Hill, 2008.
- P. R. Cullis, S. C. Semple, and M. J. Hope, “Lipid nanoparticle formulations for nucleic acid delivery,” U.S. Patent 8,492,359, Jul. 23, 2013.

THANK YOU!!!

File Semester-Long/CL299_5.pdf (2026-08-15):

LNP Manufacturing and Process Simulation; CL 299 presentation 5; Supervisor:; Prof. Kaustubh S. Rane Department of Chemical Engineering; Presented by:; Rhythem Soni 24110296 Aman Bola 24110032 Saket Jonwal 24110311

## Energy Balance

Equipment | Typical Lab Power Range
Syringe pump | | 5–20 W
Magnetic stirrer | | 5–15 W
Peristaltic pump | | 20–60 W
TFF circulation pump | | 80–120 W

Ptotal = 200 W
Energy consumption of the system is calculated using the equation:

E = P × t
E = 0.22 kWh

What is in the Code?; removal.

- A Python-based simulator that takes feed compositions and flow rates as input and automatically calculates every stream in the process — including TFF splits and ethanol

What You Input in the Code; • Molar Ratios — Organic Phase Ionizable Lipid Helper Lipid Cholesterol PEG Lipid Cholesterol Ratios converted to wt% using MW of each component; • Molar Ratios — Aqueous Phase mRNA Buffer Absolute concentrations set separately as mg/mL inputs; • Feed Flow Rates Aqueous feed flow (mL/min) Organic feed flow (mL/min) Changing these two values changes every downstream flow automatically; • Feed Concentrations mRNA conc in aqueous feed (mg/mL) Buffer salt conc (mg/mL); • Process Parameters; Encapsulation efficiency; (fraction, e.g.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

Total lipid conc in organic feed (mg/mL)

Key Equations Used in the Model; Mole Fraction → Mass Fraction wfᵢ = (xᵢ × MWᵢ) / Σ(xⱼ × MWⱼ); Diafiltration Ethanol Removal (C = C₀ · e⁻ᴺ) C_ethanol = C₀ × exp(−N) Standard diafiltration washout equation. N = number of diavolumes. N=5 → 99.3% removal. Used in FDA submissions and industry protocols.; Dilution Buffer Calculation V_dil = V_EtOH / (target% / 100) − V_S12 Back-calculates dilution buffer volume; for any FRR.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

required to reduce ethanol from post-mixer level to target vol%. Adjusts automatically

# Sample Output (aq = 9 mL/min, org = 3 mL/min)

Stream | Flow (mL/min) | Ethanol (vol%) | LNP Mass Flow (mg/min)
Aqueous Feed | 9.00 | — | 2.70 (mRNA)
Organic Feed | 3.00 | 98.7% | 30.00 (lipids)
Crude LNP (S12) | 12.00 | 24.7% | 32.70
Dilution Buffer | 25.02 | — | —
Diluted LNP (S13) | 37.02 | 8.0% | 32.70
DF Buffer → TFF | 37.02 | — | —
TFF Permeate | 66.64 | ~99%→0 | 1.65 (lost)
TFF Retentate | 7.40 | 0.2% | 29.28
Final Product | 7.40 | 0.2% | 29.28
Balance Error
0%

Encapsulated mRNA Recovery 89.1%

Ethanol Removed (N=5 diavolumes) 99.33%

What the Simulator Outputs; • Feed Streams Flow rate (mL/min) Concentration of each component (mg/mL) Mass flow of each component (mg/min); • Final Product Stream Final product flow rate (mL/min); Mass flow of each component in final product Encapsulated mRNA mass flow and recovery %; • Calculated Process Flows Dilution buffer added (auto-calculated from target ethanol %) Ethanol vol% at each stage DF buffer flow (auto-scaled from diavolumes × retentate) TFF permeate flow (auto-calculated from VRR)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

Concentration of all components in product

Sterile filter dead volume noted separately

PAT

PAT classification - INLINE; ▪ Dynamic light scattering(DLS); ▪ Zeta potential analysis; ▪ Optical turbidity measurement(turbidity probes) it detects incorrect lipid mixing aggregation and wrong molecule formation.; ▪ PVM capturing image while LNPs are forming; ▪ NIR

Now we have classification of PAT techniques used in LNP manufacturing.

measure particle size and distribution & PDI (<0.2).

measure surface charge that indicates the stability of suspension.

monitor composition and concentration of components in real time without sampling.

▪ UV–Vis Spectroscopy; Impurities.; ▪ pH sensor at the buffer mixing for correct pH.; ▪ flow meter measure flow rate of liquid streams.; ▪ temp prob; ▪ conductivity sensor buffer dilution verification.; ▪ Pressure sensor in TFF filtration.; ▪ Raman spectroscopy

it monitors Concentration of lipids, Encapsulated drug / RNA, Particle formation kinetics and

## Online

- High-Performance Liquid Chromatography (HPLC)
On-line possible via auto-samplers for drug loading, encapsulation efficiency, or degradation monitoring.
- Raman spectroscopy
used as a downstream analytical tool to measure how much mRNA is successfully encapsulated inside lipid nanoparticles.
- Charged aerosol detectors (CAD)
Used with chromatography to detect and quantify lipid components in LNP formulations that do not absorb UV light
- Refractive index (RI)
Measures changes in refractive index to detect lipids and polymers in LNP samples during chromatographic analysis.

▪ ultraviolet(UV) diode array; simultaneously recording their absorption spectra; ▪ LC-MS lipid identification and impurity detection

Detects UV-absorbing molecules such as RNA or drugs in LNP formulations while

Atline; ▪ Raman spectroscopy; ▪ Zeta potential analysis; ▪ DLS; ▪ NMR lipid structure and molecular interactions; ▪ Cryo-TEM

Visualize morphology and internal structure of LNPs
confirm nanoparticle formation and observe structure of lipid core.

## Resources:

- M. Mehta and T. A. Bui, “Lipid-Based Nanoparticles for Drug/Gene Delivery: An Overview of the Production Techniques and Difficulties Encountered in Their Industrial Development,” ACS Materials Au, vol. 3, no. 6, pp. 600–619, 2023, doi: 10.1021/acsmaterialsau.3c00032.
- J. Auclair and A. S. Rathore, “Analysis of Lipid Nanoparticles,” | LCGC North America, | vol.
41, no. 6, pp. 216–219, Jun. 2023, doi: | 10.56530/lcgc.na.ii3372s8.
- S. Jin and E. Reverdatto, “Encapsulation of mRNA in Therapeutics Like Lipid Nanoparticles Probed by Deep-UV Resonance Raman Spectroscopy,” Analytical Chemistry, vol. 97, 2025, doi: 10.1021/acs.analchem.5c04246.
- J. A. Kulkarni, D. Witzigmann, S. Chen, | P. R. Cullis, and R. van der Meel, | “On the
formation and morphology of lipid nanoparticles containing ionizable cationic lipids and
siRNA,” ACS Nano, vol. 15, no. 5, pp. 9078–9093, | May 2021, | doi:
10.1021/acsnano.1c03058.
- https://drive.google.com/drive/folders/10AyL6bArZ2kjxkyHl5krHhYheAy40hMO?usp=drive_link (https://drive.google.com/drive/folders/10AyL6bArZ2kjxkyHl5krHhYheAy40hMO?usp=drive_link)
- D. W. Green and M. Z. Southard, Perry’s Chemical Engineers’ Handbook, | 9th ed. New
York, | NY, USA: McGraw-Hill Education, | 2019.

- G. Towler and R. Sinnott, Chemical Engineering Design: Principles, Practice and Economics of Plant and Process Design, 3rd ed. Oxford, U.K.: Elsevier, 2022.
- N. M. Belliveau, J. Huft, P. J. Lin, S. Chen, A. K. K. Leung, J. B. Leaver, A. W. Wild, J. B. Lee, R. J. Taylor, Y. K. Tam, C. L. Hansen, and P. R. Cullis, “Microfluidic synthesis of highly potent limit-size lipid nanoparticles for in vivo delivery of siRNA,” Molecular Therapy – Nucleic Acids, vol. 1, no. 8, p. e37, Aug. 2012, doi: 10.1038/mtna.2012.28.
- R. van Reis and A. L. Zydney, “Membrane separations in biotechnology,” Current Opinion in Biotechnology, vol. 18, no. 3, pp. 208–211, Jun. 2007.

THANK YOU!!!

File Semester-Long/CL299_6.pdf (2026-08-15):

LNP Manufacturing and Process Simulation; CL 299 presentation 6; Supervisor:; Prof. Kaustubh S. Rane Department of Chemical Engineering; Presented by:; Rhythem Soni 24110296 Aman Bola 24110032 Saket Jonwal 24110311

# Energy

Flow Rate | Power
1–10 mL/min | | ~10 W
10–50 mL/min | | ~15–20 W

Syringe Pump :

Peristaltic Pump :

Flow Rate | Power
10–50 mL/min | | 20–40 W
50–100 mL/min | | 40–80 W

TFF circulation pump :- 80–120 W
Magnetic stirrer :- 5–15 W
Total power :- 240W

# Process Simulation Code

- This code supports both forward and backward calculation.

### Main components:

### - forward_calculation()

### - backward_calculation() → Reverse calculation

### - dof_analysis() → System solvability

### - solve() → Mode selection

### - run_simulation() → Execution + output

Forward Calculation; ▪ Input Feeds: Organic and Aqueous Flow; ▪ FRR = aq/org; ▪ Mixer = aq + org; ▪ Dilution: dilution = ratio × mixer tff_in = mixer + dilution; ▪ TFF: retentate = tff_in / VRR permeate = tff_in − retentate

### - Cryoprotectant Addition: cryo_out = retentate + cryo_flow

### - Final Filtration: product = cryo_out − dead_volume

# Backward Calculation

### - Goal: Determine required inputs from desired product

Reverse steps:

- Add back filter loss, remove cryoprotectant
- Reverse TFF using VRR, reverse dilution
- Split mixer using FRR

Final result:

- Required aqueous flow

### - Required organic flow

- Mixer conditions

Simulation Workflow; ▪ Function: run_simulation(); Steps:; ▪ Read JSON input; ▪ Create run folder; ▪ Execute solver; ▪ Save outputs:; ▪ output.txt; ▪ diagnostics.txt; ▪ Zip all results

# PAT AS CONTROL SYSTEM

### - pH sensor

### - flow meter

### - temp prob

### - conductivity sensor

### - Pressure sensor

PAT NOT AS CONTROL SYSTEM; ▪ DLS; ▪ Zeta potential analysis; ▪ Optical turbidity measurement; ▪ PVM; ▪ NIR; ▪ UV-Vis spectroscopy; ▪ Raman spectroscopy; ▪ HPLC; ▪ Charged aerosol detectors; ▪ UV diode ray; ▪ NMR; ▪ Cryo-TEM

UNIVERSAL PAT FOR LNP MANUFACTURING; ▪ DLS; ▪ Zeta Potential analysis; ▪ pH sensor; ▪ flow meter; ▪ temp prob; ▪ conductivity sensor; ▪ Pressure sensor; ▪ Fluorescence-based assays; ▪ Cryo-TEM; ▪ Size Exclusion Chromatography

# Resources

- A. N. Joshi, S. Hudson, and V. V. Ranade, “Continuous manufacturing of lipid nanoparticles: Influence of device designs and operating parameters,” Chemical Engineering Science, vol. 323, p. 123140, Dec. 2025, doi: 10.1016/j.ces.2025.123140.
- Y. Matsuura-Sawada, M. Maeki, T. Nishioka, A. Niwa, J. Yamauchi, M. Mizoguchi, K. Wada, and M. Tokeshi, “Microfluidic device-enabled mass production of lipid-based nanoparticles for applications in nanomedicine and cosmetics,” ACS Applied Nano Materials, vol. 5, no. 6, pp. 7867–7876, 2022, doi: 10.1021/acsanm.2c00886.
- D. C. Jürgens, L. Deßloch, D. Porras-Gonzalez, J. Winkeljann, S. Zielinski, M. Munschauer, A. L. Hörner, G. Burgstaller, B. Winkeljann, and O. M. Merkel, “Lab-scale siRNA and mRNA LNP manufacturing by various microfluidic mixing techniques – an evaluation of particle properties and efficiency,” OpenNano, vol. 12, p. 100161, 2023, doi: 10.1016/j.onano.2023.100161.
- Y. Eygeris, M. I. Henderson, A. G. Curtis, A. Jozić, J. Stoddard, R. Reynaga, K. R. Chirco, G. Li-Na Su, M. Neuringer, A. K. Lauer, R. C. Ryals, and G. Sahay, “Preformed vesicle approach to LNP manufacturing enhances retinal mRNA delivery,” Small, vol. 20, no. 37, p. e2400815, 2024, doi: 10.1002/smll.202400815
- K. Nag, M. E. H. Sarker, S. Kumar, et al., “DoE-derived continuous and robust process for manufacturing of pharmaceutical-grade wide-range LNPs for RNA-vaccine/drug delivery,” Scientific Reports, vol. 12, p. 9394, 2022, doi: 10.1038/s41598-022-12100-z. Harvard Apparatus, Pump 11 Elite Syringe Pump User Manual, Holliston, MA, USA, 2018.
- Cole-Parmer, Masterflex L/S Peristaltic Pump Drive Datasheet, Vernon Hills, IL, USA, 2020.
- D. W. Green and M. Z. Southard, Perry’s Chemical Engineers’ Handbook, 9th ed. New York, NY, USA: McGraw-Hill, 2019.

THANK YOU!!!

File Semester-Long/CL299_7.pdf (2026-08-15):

LNP Manufacturing and Process Simulation; CL 299 presentation 7; Supervisor:; Prof. Kaustubh S. Rane Department of Chemical Engineering; Presented by:; Rhythem Soni 24110296 Aman Bola 24110032 Saket Jonwal 24110311

## Energy

Flow Rate | Power
1–10 mL/min | | ~10 W
10–50 mL/min | | ~15–20 W

Syringe Pump :

Peristaltic Pump :

Flow Rate | Power
10–50 mL/min | | 20–40 W
50–100 mL/min | | 40–80 W

TFF circulation pump :- 80–120 W
OverHead Stirrer :- 50–100 W
Magnetic stirrer :- 5–15 W
Total power :- 695W

PAT AS P&ID; ▪ Level Indicator(LI); ▪ Flow Transmitter; ▪ Valve; ▪ Temperature transmitter; ▪ Low flow valve; ▪ Pressure transmitter; ▪ Flow controller; ▪ Conductivity sensor; Some elements that we use in the P&ID.

▪ pH Controller; ▪ Emergency Shutdown (ESD); ▪ Process line; ▪ Differential Pressure Indicator; ▪ pH transmitter; ▪ Pressure controller; ▪ Control loop line

Why there is no Cooling for Mixer?; ▪ We have Low flow rate

- There is not much increment in temperature at lab scale

Resource; therapies,” Molecular Therapy, 2017; US Patent US20180208676A1, 2018; US6874900B2, Apr. 5, 2005.

- P. R. Cullis and M. J. Hope, “Lipid nanoparticle systems for enabling gene
- K. A. Whitehead et al., “Formulations and methods for delivery of nucleic acids,”
- J. R. Bourne and R. G. K. Friberg, “Mixing apparatus and method,”
- J. R. M. Clark et al., “Bioreactor mixing system,” US20110223636A1, Sep. 15,
- D. J. McCarthy, “Agitation system with impeller,” US20100060325A1, Mar. 11,

THANK YOU!!!

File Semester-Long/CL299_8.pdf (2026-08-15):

LNP Manufacturing and Process Simulation; CL 299 presentation 8; Supervisor:; Prof. Kaustubh S. Rane Department of Chemical Engineering; Presented by:; Rhythem Soni 24110296 Aman Bola 24110032 Saket Jonwal 24110311

PAT

TYPES OF CONTROLLER USED IN P&ID; process streams.; ▪ Select a Master Stream.; follower stream.; Ffollower = Ratio; ∗ FMaster; ▪ Useful → Wrong ratio is major risk.; RATIO CONTROLLER

### - A specialized control strategy used to maintain a fixed ratio between two or more

- Divide the flow according to Master stream.

### - The controller calculates the setpoint for the

HOW WE USE RATIO CONTROLLER ?; ▪ S1 as master stream → Measure.; ▪ Measured stream to be adjusted.; ▪ Send signals to other controllers.; ▪ Then divide the flow. S2 = 0.2 * S1

Feedback Controller; ▪ Closed-loop control strategy.; setpoint.; back to the setpoint.

### - output of a process is continuously measured by a sensor, compared to a desired

### - the error is used to automatically adjust the manipulated variable to bring the process

HOW WE USE FEEDBACK CONTROLLER?; and generates an error signal; back to setpoint

- pH transmitter continuously measures solution
- Controller compares measured pH to setpoint
- Error drives acid or base valve to bring pH


# On/Off ( bang-bang) Controller

- Close loop control strategy.

## - The controller output has only two possible states: Fully ON or Fully OFF

## - A switching action is triggered when the measured variable crosses a

preset threshold.

- Implemented as part of a Safety Instrumented System (SIS).

HOW WE USE On/Off CONTROLLER?; ▪ FSL-101 or FSL-102 drops below trip setpoint.; ▪ ESD activates.; ▪ full process shutdown

## Resources

- G. Dragffy, “The design of a highly reliable safety critical emergency shutdown (ESD) system,” Reliability Engineering & System Safety, 1998.
- N. K. Drunasky and B. J. Hackel, "PID controls: the forgotten bioprocess parameters," Discov. Chem. Eng., vol. 2, no. 1, p. 1, Jan. 2022, doi: 10.1007/s43938-022-00008-z.
- C. B. Roces et al., "Manufacturing considerations for the development of lipid nanoparticles using microfluidics," Pharmaceutics, vol. 12, no. 11, Nov. 2020, Art. no. 1095, doi: 10.3390/pharmaceutics12111095.
- P. Woolf et al., "11.4: Ratio control- What is it? When useful? When not? Common usage," in Chemical Process Dynamics and Controls, Davis, CA, USA: LibreTexts, Jul. 2022. [Online].
- S. Singh, R. Ierapetritou, and F. J. Muzzio, “Closed-loop feedback control of a continuous pharmaceutical tablet manufacturing process via wet granulation,” Journal of Pharmaceutical Innovation, vol. 9, no. 2, pp. 137–152, 2014, doi: 10.1007/s12247-014-9170-9.

Innov 12, 327–346 (2017). https://doi.org/10.1007/s12247-017-9297-6.; ▪ https://aiche.confex.com/aiche/2016/webprogram/Paper471687.html

- Su, Q., Moreno, M., Giridhar, A. et al. A Systematic Framework for Process Control Design and Risk Analysis in Continuous Pharmaceutical Solid-Dosage Manufacturing. J Pharm

THANK YOU!!!

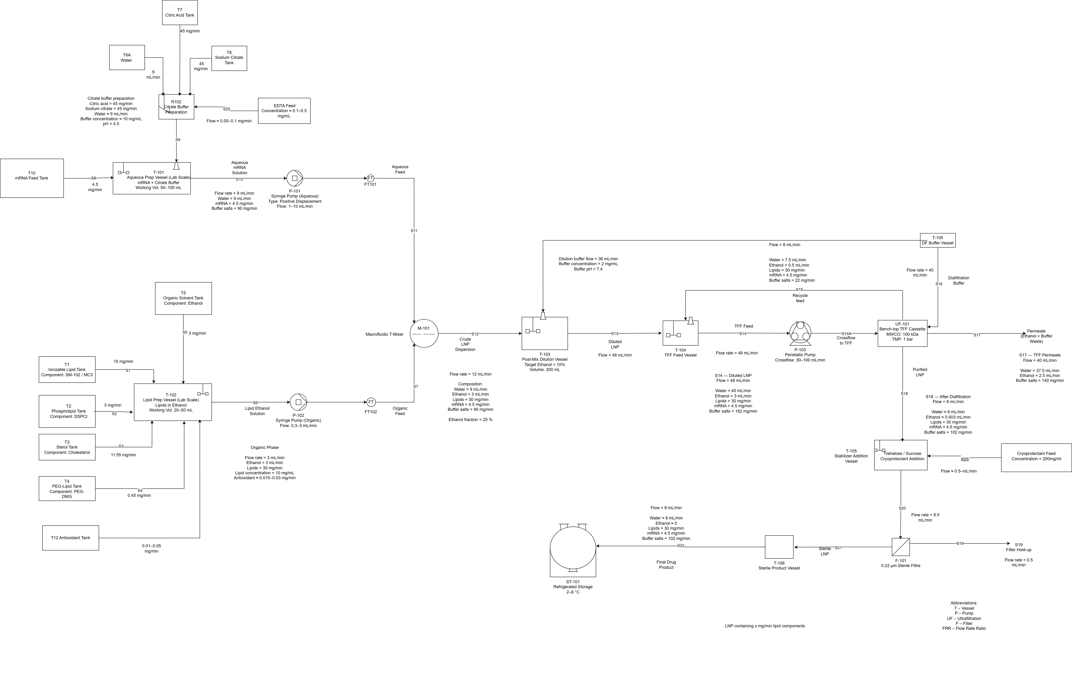
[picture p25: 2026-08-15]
Semester-Long/Final PFD.png

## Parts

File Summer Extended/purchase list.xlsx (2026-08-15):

RECEIVED | NO NEED TO ORDER
Pumps (2 pumps)
Part Number | Item Description | Packages for 2 pumps | Items per pack | Total | Price per Pack (approx) | Total price | amazon link
1 | Nema 17 Stepper Motor (Bipolar, 40mm, 45Ncm) | 1 | 2 | 2 | 499 | 998 | 998 |  | received
2 | 5mm to 5mm Motor Shaft Coupling | 2 | 1 | 2 | 189 | 378 | https://www.amazon.in/Robodo-Electronics-PR64-Aluminium-Flexible/dp/B0787JNN4R?nsdOptOutParam=true | Received on May 20
3 | 6mm Steel Rod (length 200mm, pack of 2) | 2 | 2 | 4 | 2268 | 4536 | https://www.amazon.in/Eowpower-Stainless-Steel-200mm-Turning/dp/B072JPQX4Q |  | received
4 | 6mm Linear Bearing (pack of 4) | 1 | 4 | 4 | 599 | 599 | https://www.amazon.in/3D-Innovations-CHPSS654-Bearings-Application/dp/B07FZ49X8W?nsdOptOutParam=true | Received on May 20
~~5~~ | ~~M5x0.8 Threaded Rod (length 170mm)~~ | ~~1~~ | ~~5~~ | ~~5~~ | ~~1368~~ | ~~1368~~ | https://www.amazon.in/Sellify-170mm-Stainless-Threaded-Fasteners/dp/B01M4L8JDC?nsdOptOutParam=true
6 | M5x0.8 nut | 1 | 20 | 20 | 200 | 200 | https://www.amazon.in/Stainless-Steel-Thread-Size-Pack/dp/B0FHFS4ZM8?nsdOptOutParam=true | RECEIVED ON MAY 21
7 | M3x0.5 socket head screws to mount motor (length 20mm) | 3 | 10 | 30 | 349 | 1047 | https://www.amazon.in/Sci-Eng-Tech-M3-Allen-Screws-Socket/dp/B0BQYHYNXD?nsdOptOutParam=true | RECEIVED ON MAY 22
8 | M3x0.5 socket head screws (hold rod in place, length 10mm) | 1 | 55 | 55 | 3082 | 3082 | https://www.amazon.in/M3-10-55pcs-Generic-M3x10mm-Stainless/dp/B01MFA9YEP?nsdOptOutParam=true
9 | M3 nut (hold rod in place) | 3 | 12 | 36 | 74 | 222 | https://www.amazon.in/Nut-Threaded-3mm-8-Pieces-Pack/dp/B09J92WY5Q | RECEIVED ON MAY 19
10 | M5 knob (hold syringe in place) | 1 | 2 | 2 | 499 | 499 | https://www.amazon.in/GK-MART-Diameter-Bakelite-Suitable/dp/B0CP7M3KTS
11 | 12V power unit (end stripped to fit CNC shield power input) | 1 | 1 | 1 | 759 | 759 | https://www.amazon.in/FEDUS-Adapter-Converter-Battery-Transformer/dp/B0CDM8586S | Received on May 18
12 | Arduino + CNC Shield Pack | 1 | 1 | 1 | 1999 | 1999 | https://www.amazon.in/REES52-Expansion-Stepper-Heatsink-Compatible/dp/B0B7P9TV3T?nsdOptOutParam=true | Received on May 19
SUPPORTING PARTS PRINTING
 |  |  | price | purchase link
1 | PLA filament | 1kg | 1599 | https://robu.in/product/hyper-pla-3d-printing-filament-1-75mm-1kg-white/ | Received on May 18
Microscope
Part Number | Item Description | Packages needed | Required Items | Total | Price per Pack (approx) | Total price
1 | Raspberry Pi Motherboard | 1 | 1 | 1 | 2 options: 1. Raspberry Pi 4 Model B Kit 2. Raspberry Pi 3 Model B+ Kit
2 | Raspberry Pi Power Suppy (5v 1.5A DC) | 1 | 1 | 1 |  | 15000 | https://www.amazon.in/Raspberry-Model-LAN-mHDMI-Supply-MicroSD/dp/B0C7N5JXCY
3 | 16gb MicroSD card (comes with adapter) | 1 | 1 | 1 |  | 6499
4 | Raspberry Pi 7" touchscreen display | 1 | 1 | 1 | 6363 | 6363 | https://www.amazon.in/Hosyond-Display-1024%C3%97600-Capacitive-Raspberry/dp/B09XKC53NH
5 | USB Microscope | 1 | 1 | 1 | 1578 | 1578 | https://www.amazon.in/Jiusion-Microscope-Cellphone-Magnification-Endoscope/dp/B09653SCG6
6 | Keyboard + Mouse Bundle (wired) | 1 | 1 | 1 | 985 | 985 | https://www.amazon.in/Logitech-Keyboard-Windows-Full-Size-Compatible/dp/BOO4X191EQ?nsdOptOutParam=true
7 | M3x0.5 Socket Head Screws (length 10mm) | 1 | 4 | 4 | No need to purchase
8 | M5x0.8 Socket Head Screw (length 14mm) | 1 | 8 | 8
9 | M5x0.8 nuts | 1 | 8 | 8
SUPPORTING PARTS PRINTING
 |  | amount | price | link | Ordered?
1 | PETG FILAMENT | 1 KG | 1343 | https://robu.in/product/esun-petg-1-75mm-3d-printing-filament-1kg-natural/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 | Arrived
2 | Syringes | 1 Package | 469 | https://www.amazon.in/dp/B0FHHFT431 | Yes
3 | PTFE tube | 2 | 954 | https://www.amazon.in/Enakshi%C2%AE-Printer-Filament-3-0mm-Collectibles/dp/B0FMYL65B1 | Yes (Ordered 3)
4 | PTFE Sheet | 1 | 1349 | https://www.amazon.in/Priyanshu-Decor-Transparent-Temperature-Resistance/dp/B0BXFLNM36 | Yes
5 | sand paper | 1 | 120 | https://www.amazon.in/ikis-Sanding-Sandpaper-Grit-80-Pieces/dp/B0BVN1H59B | Yes
6 | CNC Shield version 3 | 1 | 205 | https://www.amazon.in/ROBODUINO-Engraving-Machine-Printer-expansion/dp/B0GSB589MQ | Yes
7 | M5 Threaded Rod | 1 | 1099 | https://www.amazon.in/Feelers-Stainless-Threaded-Threads-Length%E3%80%90Pack/dp/B092Q9FD13 | Yes
8 | DC Power Jack Female Adapter |  |  | https://www.amazon.in/DC-Power-Socket-Jack-Connector/dp/B0BHR27D5D?nsdOptOutParam=true | Yes
9 | PLA Filament | 1kg | 1599 | https://robu.in/product/hyper-pla-3d-printing-filament-1-75mm-1kg-white/ | Yes (Ordered from Amazon. Out of stock on robu.in)
10 | M5 threaded rod | 1 | 1099 | https://www.amazon.in/Feelers-Stainless-Threaded-Threads-Length%E3%80%90Pack/dp/B092Q9FD13 | Yes
11 | Nema 17 stepper motor | 1 | 998 | https://www.amazon.in/Robodo-Electronics-PR17-Stepper-Robotics/dp/B0787HCJXN | Yes (Ordered 2)
12 | 5mm to 5mm motor shaft coupling | 2 | 398 | https://www.amazon.in/Robodo-Electronics-PR64-Aluminium-Flexible/dp/B0787JNN4R?nsdOptOutParam=true | Yes (Ordered 2)
13 | Linear bearing(PACK of 4) | 1 | 599 | https://www.amazon.in/3D-Innovations-CHPSS654-Bearings-Application/dp/B07FZ49X8W?nsdOptOutParam=true | Yes
14 | Syringes | 1 | 469 | https://www.amazon.in/dp/B0FHHFT431 | Yes
15 | O rings | 1 |  | https://amzn.in/d/02FwbIIF | Yes

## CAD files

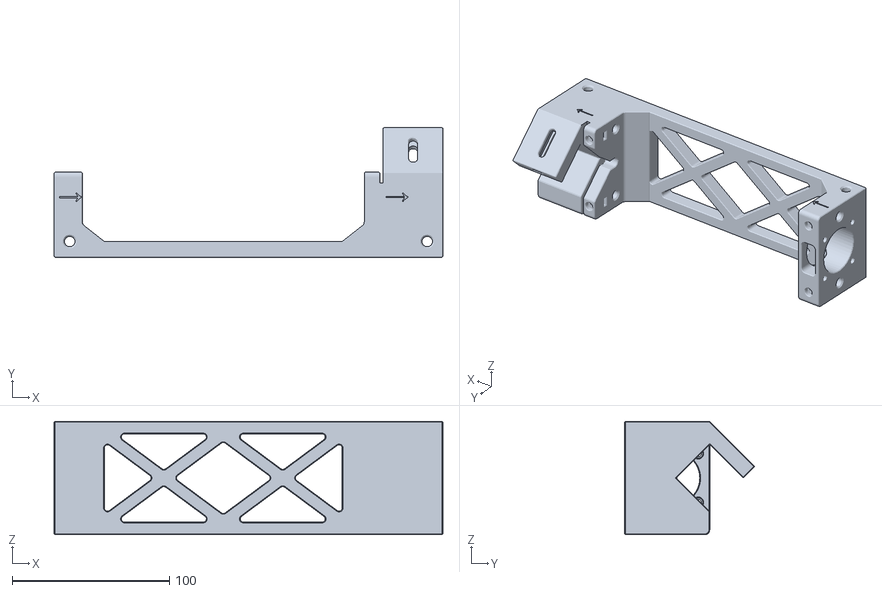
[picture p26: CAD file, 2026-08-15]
Summer Extended/Mixer Dimension and references/pump_final.stl
247.0 x 82.3 x 72.0

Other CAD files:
Summer Extended/Mixer Dimension and references/Mixer_TOP.ipt
Summer Extended/Mixer Dimension and references/Outlet_screw.ipt
Summer Extended/Mixer Dimension and references/inlet_screw.ipt
Summer Extended/Mixer Dimension and references/mixer_MIVM.ipt

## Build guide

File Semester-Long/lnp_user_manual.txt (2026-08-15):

  LNP MANUFACTURING PROCESS SIMULATION
  USER MANUAL

  WHAT THIS SIMULATION DOES

  This simulation models a continuous lab-scale LNP (Lipid Nanoparticle)
  manufacturing process. It calculates:
    - Flow rates of every stream in the process (Section A)
    - Concentration (mg/mL) and mass flow rate (mg/min) of every component
      in every stream (Sections B and C)

  The five process steps covered:
    Step 1   Microfluidic Mixing               M-101 T-Mixer
    Step 2   Buffer Dilution                   T-103 Post-Mix Dilution Vessel
    Step 3   Tangential Flow Filtration        UF-101, 100 kDa MWCO
    Step 4   Cryoprotectant Addition           T-100 Stabilizer Vessel
    Step 5   Sterile Filtration                F-101, 0.22 um Filter

  You fill in ONE file (lnp_input.txt), run ONE command, and all results
  are saved automatically.

  YOUR FILES  (keep all four in the same folder)

    lnp_simulation.py          Main script. Runs the flow rate calculation.
    lnp_composition.py         Composition script. Runs automatically after the main script.
    lnp_input.txt              The only file you fill in.
    lnp_user_manual.txt        This manual.

  Do not rename any of these files.

  STEP 1   INSTALL PYTHON AND NUMPY  (one-time setup)

  Check if Python is installed. Open a terminal:
    Windows: press Windows key, type cmd, press Enter
    Mac: open Terminal from Applications > Utilities
  Type:
    python --version
  If you see Python 3.x.x, Python is installed. If not, download it from python.org.

  Install numpy (required for the matrix solver):
    pip install numpy
  You only need to do this once.

  STEP 2   OPEN THE INPUT FILE

  Open lnp_input.txt in any plain text editor.
    Windows: right-click the file, Open with, Notepad
    Mac: right-click, Open with, TextEdit (then Format > Make Plain Text)

  The file has three sections:
    SECTION A   Flow rates — required to run the simulation
    SECTION B   Feed stream compositions — optional, for concentration calculations
    SECTION C   Final product composition — optional, for back-calculation or verification

  STEP 3   FILL IN THE INPUT FILE

  For every parameter you know, type the number after the equals sign:
    flow_aqueous_mL_min = 9

  For every parameter you do not know (you want it calculated), leave it blank:
    flow_aqueous_mL_min =

  Four parameters are REQUIRED and must always have a value:
    dilution_ratio                    (how much buffer is added per unit mixer output)
    tff_vrr                           (TFF Volume Reduction Ratio)
    cryo_flow_mL_min                  (cryoprotectant addition flow rate)
    sterile_filter_dead_vol_mL_min    (sterile filter dead volume)

  Rules:
    Numbers only in the value field. No units, no text.
    Blank means unknown. Zero (0) means the value is zero. They are different.
    Do not change the parameter names on the left side of =
    Text after the | symbol is for reference only. The code ignores it.

  STEP 4   HOW MANY VALUES DO YOU NEED IN SECTION A

  The flow system has 9 flow variables and 7 equations.
  You must provide at least 2 known flow values for a unique solution (DOF = 0).
  The 4 REQUIRED parameters do not count toward this minimum.

  DOF = 0    Exactly determined. Unique solution. This is what you want.
  DOF > 0    Not enough values. The code tells you what is missing.
  DOF < 0    More values than needed. The extra values are used to cross-check
             your inputs. The code tells you if they are consistent.

  STEP 5   RUN THE SIMULATION

  Open your terminal and navigate to the folder containing your files:
    Windows:    cd C:\Users\YourName\YourFolder
    Mac/Linux:  cd /Users/YourName/YourFolder

  Run:
    python lnp_simulation.py
  or if that gives an error:
    python3 lnp_simulation.py

  That is all. Both the flow calculation and the composition calculation run
  automatically from a single command.

  STEP 6   FIND YOUR RESULTS

  A new numbered folder is created every time you run:
    simulation_runs/run_001/
    simulation_runs/run_002/
    (each run gets its own folder — nothing is overwritten)

  Files inside each run folder:

    input_used.txt          Copy of the input file used for that run
    output_report.txt       Flow rate results, DOF analysis, material balance
    diagnostics.txt         Solver details, equation reference, step-by-step log
    composition_report.txt  Concentration and mass flow for all streams
                            (only created if Section B or C was filled in)

  SECTION B AND C: COMPOSITION CALCULATIONS

  For each component in each stream, the fundamental equation is:
    mass_flow (mg/min) = concentration (mg/mL) x flow_rate (mL/min)

  You provide concentration OR mass flow for each component.
  The other is calculated automatically.

  If you provide both concentration and mass flow:
    The code checks if  mass = concentration x flow rate  is satisfied.
    If it is not, a WARNING is shown. The flow rate model (Section A)
    is always the authority. Your mass flow value will NOT change the flow rates.

  KEY FORMAT:
    stream.component.field = value

  stream is one of:
    aqueous           organic           dilution_buffer           cryo_feed
  For Section C:
    final_product

  field is one of:
    conc_mg_mL        (concentration in mg per mL)
    mass_mg_min       (mass flow rate in mg per minute)

  Example:
    aqueous.mRNA.conc_mg_mL = 0.1
    organic.Ionisable_Lipid.conc_mg_mL = 10.0
    final_product.mRNA.conc_mg_mL = 0.1069

  You do NOT fill in anything for mixer output, TFF retentate, TFF permeate,
  or the final product in Section B. These are calculated automatically.

  WHAT THE COMPOSITION MODULE CALCULATES

  TFF separation uses realistic efficiency fractions, not ideal 100% cuts:
    mRNA                   95% retained in retentate,  5% lost to permeate
    Lipids (IL, DSPC, Chol, PEG)   98% retained,  2% to permeate
    Ethanol                 5% retained, 95% removed to permeate
    Buffer salts            2% retained, 98% removed to permeate
    Water                  10% retained, 90% removed to permeate

  Adjust these in the TFF_RETENTION_FRACTION table at the top of lnp_composition.py
  if you have experimental data for your specific process.

  Section B only (feed data given):
    Calculates mixer output, TFF retentate, TFF permeate, and final product
    concentrations and mass flows by forward propagation.

  Section C only (final product data given):
    Back-calculates the required feed stream concentrations using the TFF
    retention fractions in reverse. Useful when you know your target
    product specification and want to know what feed concentrations you need.
    Note: Water, buffer salts, and dilution buffer components cannot be
    back-calculated from final product alone (they come from multiple streams).

  Both B and C given:
    Calculates forward from Section B, then compares the result to Section C.
    Any discrepancy greater than 5% triggers a WARNING per component.
    Useful to verify that your feed and product data are physically consistent.

  ALL TYPES OF CALCULATIONS SUPPORTED

  The simulation supports seven different calculation scenarios:

  Type 1   FORWARD (flow rates only)
           Provide aqueous and organic pump settings. Get all downstream flows.
           Minimum input: flow_aqueous_mL_min and flow_organic_mL_min (plus REQUIRED)

  Type 2   BACKWARD (flow rates only)
           Provide target final product flow plus one upstream value.
           The code calculates what pump settings are needed.
           Minimum input: final_product_mL_min and one of (flow_organic, flow_aqueous, or FRR)

  Type 3   GENERAL mid-process (flow rates only)
           Provide any combination of known flow values from anywhere in the process.
           The code solves all unknowns simultaneously.
           Example: know FRR and organic flow, want everything else.

  Type 4   FORWARD with composition
           Sections A + B filled. Flow rates + feed concentrations given.
           All stream compositions calculated forward.

  Type 5   BACKWARD composition
           Section A filled, Section C filled, Section B blank.
           Back-calculates required feed concentrations from final product target.

  Type 6   BOTH (composition verification)
           Sections A, B, and C all filled.
           Forward-calculates from feed (B) and checks if result matches product (C).

  Type 7   Composition drives flow rate (reverse path)
           Section A has some blank flow values. Section B has both conc AND mass
           for those streams. The code derives the flow rate as mass / concentration,
           then uses it in the flow solver. This replaces providing the flow in Section A.
           Example: you know mRNA conc = 0.1 mg/mL and mRNA mass flow = 0.9 mg/min
           in the aqueous stream. The code derives aqueous flow = 0.9 / 0.1 = 9 mL/min.

  WARNINGS AND ERRORS

  [!! ERROR !!]
    A physically impossible value was found (negative flow, concentration, or mass flow).
    The simulation stops. Fix the value and re-run.

  [** WARNING **]
    A value is outside the realistic operating range for that variable.
    The simulation continues. Review the flagged value.

  [-- ADVISORY --]
    A value is outside the typical range but within realistic limits.
    May be intentional. Review if unexpected.

  [WARNING] Inconsistency detected
    You gave both concentration and mass flow for a component, and they
    do not agree with the flow rate from Section A.
    The flow rate model is the authority. The mass flow value in Section B
    is overridden by conc x flow rate. Your flow rates are NOT changed.

  [WARNING] Total concentration exceeds 1100 mg/mL
    The sum of all component concentrations in a stream is physically
    unrealistic (water alone is ~1000 mg/mL). Check your concentration inputs.

  [WARNING] Final product mismatch
    Section B and Section C data produce inconsistent final product values.
    Check your feed concentrations or your final product specification.

  [SOLVER ERROR] UNDER-DETERMINED SYSTEM
    You did not provide enough known flow values. The error message tells you
    exactly how many more values you need to provide in Section A.

  [INFO] Flow rate derived from composition
    The code successfully derived a stream flow rate from your Section B
    mass flow and concentration data. This is informational, not an error.

  WORKED EXAMPLES

  The following examples show exactly what to fill in for each of the
  seven calculation types.

  Example 1: FORWARD (Type 1) — know pump settings, want all downstream flows
  Set in Section A:
    flow_aqueous_mL_min = 9
    flow_organic_mL_min = 3
    dilution_ratio = 3
    tff_vrr = 6
    cryo_flow_mL_min = 0.5
    sterile_filter_dead_vol_mL_min = 0.5
    (everything else blank)
  Expected results:
    FRR = 3.0, Mixer = 12.0 mL/min, Dilution = 36.0 mL/min
    TFF Feed = 48.0 mL/min, Retentate = 8.0 mL/min, Permeate = 40.0 mL/min
    After cryo = 8.5 mL/min, Final product = 8.0 mL/min

  Example 2: BACKWARD (Type 2) — know target product, find required pump settings
  Set in Section A:
    flow_organic_mL_min = 3
    final_product_mL_min = 8
    dilution_ratio = 3
    tff_vrr = 6
    cryo_flow_mL_min = 0.5
    sterile_filter_dead_vol_mL_min = 0.5
    (everything else blank)
  Expected results:
    flow_aqueous_mL_min = 9.0 mL/min (the required pump setting)
    All other flows same as Example 1.

  Example 3: GENERAL (Type 3) — mid-process values known
  Set in Section A:
    FRR = 3
    flow_organic_mL_min = 3
    dilution_ratio = 3
    tff_vrr = 6
    cryo_flow_mL_min = 0.5
    sterile_filter_dead_vol_mL_min = 0.5
    (everything else blank)
  FRR + Organic flow -> Aqueous = 9 mL/min derived.
  All flows calculated same as Example 1.

  Example 4: FORWARD with composition (Type 4) — feed concentrations given
  Section A: same as Example 1.
  Section B additions:
    aqueous.mRNA.conc_mg_mL = 0.1
    aqueous.Citric_Acid.conc_mg_mL = 8.4
    aqueous.Water.conc_mg_mL = 985.0
    organic.Ionisable_Lipid.conc_mg_mL = 10.0
    organic.Ethanol.conc_mg_mL = 789.0
    cryo_feed.Trehalose.conc_mg_mL = 200.0
    cryo_feed.Water.conc_mg_mL = 800.0
  Calculated results in composition report:
    mRNA in aqueous:        0.1000 mg/mL,  0.9000 mg/min
    mRNA in final product:  0.1069 mg/mL,  0.8550 mg/min  (95% of 0.9 retained)
    Ionisable lipid FP:     3.7500 mg/mL, 30.0000 mg/min  (98% of 30 retained)

  Example 5: BACKWARD composition (Type 5) — back-calculate from product target
  Section A: same as Example 1.
  Section C:
    final_product.mRNA.conc_mg_mL = 0.1069
    final_product.Ionisable_Lipid.conc_mg_mL = 3.75
    final_product.Trehalose.conc_mg_mL = 12.5
  Expected back-calculated results:
    aqueous.mRNA.conc back-calculated:        ~0.1000 mg/mL
    organic.Ionisable_Lipid.conc back-calc:   ~10.20 mg/mL
    cryo_feed.Trehalose.conc back-calc:       200.0 mg/mL

  Example 6: BOTH (Type 6) — verify feed produces expected product
  Section A: same as Example 1.
  Section B: same as Example 4.
  Section C: same as Example 5.
  Expected: Final product values are CONSISTENT (within 5%).
  If you change Section C to mRNA = 5.0 mg/mL (wrong), you will see:
    WARNING: Final product mismatch for mRNA (conc):
    calculated = 0.1069 mg/mL, user given = 5.0000 mg/mL,
    relative difference = 97.9%

  Example 7: Composition drives flow rate (Type 7)
  Leave flow_aqueous_mL_min blank in Section A (give flow_organic = 3).
  Section B:
    aqueous.mRNA.conc_mg_mL = 0.1
    aqueous.mRNA.mass_mg_min = 0.9
    aqueous.Water.conc_mg_mL = 985.0
    aqueous.Water.mass_mg_min = 8865.0
  The code derives: aqueous flow = 0.9 / 0.1 = 9.0 mL/min
  and uses this automatically in the flow solver.
  You will see: [INFO] Flow rate derived from composition: Aqueous = 9.0000 mL/min

  MATERIAL BALANCE EQUATIONS (for reference)

  All flow calculations are based on these 7 linear equations:
    EQ1   Aq + Org = Mixer Output
    EQ2   Dilution Flow = dilution_ratio x Mixer Output
    EQ3   Mixer Output + Dilution Flow = TFF Feed
    EQ4   TFF Feed = tff_vrr x Retentate
    EQ5   TFF Feed = Retentate + Permeate
    EQ6   Retentate + cryo_flow = After Cryo Flow
    EQ7   After Cryo Flow - dead_vol = Final Product
    FRR   FRR = Aqueous / Organic  (resolved analytically before matrix solve)
    Overall:  Aq + Org + Dilution + Cryo = Final Product + Permeate + Dead Volume

  All equations are linear. The solver uses numpy.linalg.lstsq for direct solution.
  No iterative method is needed.

  For composition:
    mass_flow (mg/min) = concentration (mg/mL) x flow_rate (mL/min)
  This is verified for every component where all three values are known.

  FILE AND FOLDER STRUCTURE AFTER RUNNING

  Before running:
    lnp_simulation.py
    lnp_composition.py
    lnp_input.txt
    lnp_user_manual.txt

  After running:
    simulation_runs/
      run_001/
        input_used.txt             Your input file (copy kept for records)
        output_report.txt          Flow rate results
        diagnostics.txt            Solver technical details
        composition_report.txt     Composition and mass results (if B or C filled)
      run_002/
        ...

  END OF USER MANUAL

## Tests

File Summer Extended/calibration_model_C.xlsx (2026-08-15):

Mass of water (g) | error in mass | Steps | Acceleration (steps/sec^2) | Speed (steps/sec) | Flow Rate (ml/min) | Time (sec) | density | Mass of water | Flow rate Reading 2 | time
56.13 | 0.15 | 22000 | 200 | 1050 | 139.8511195 | 23.5 | 0.97586 | 53.87 | 138.5841253 | 22.76
56.07 |  |  |  | 1029 | 138.8155692 | 23.65 | 0.97586
55.83 |  |  |  | 1008 | 136.2056595 | 24 | 0.97586 | 55 | 130.0621163 | 24.76
55.32 |  |  |  | 987 | 131.2428895 | 24.68 | 0.97586
55.88 |  |  |  | 966 | 130.8745363 | 25 | 0.97586 | 52.42 | 132.0686262 | 23.24
54.1 |  |  |  | 945 | 125.4014869 | 25.26 | 0.97586
55.92 |  |  |  | 924 | 126.7107381 | 25.84 | 0.97586 | 54.35 | 121.9264161 | 26.1
55.94 |  |  |  | 903 | 123.5991134 | 26.5 | 0.97586
55.95 |  |  |  | 882 | 121.3319267 | 27 | 0.97586
55.75 |  |  |  | 861 | 118.7000618 | 27.5 | 0.97586
55.39 |  |  |  | 840 | 115.8276116 | 28 | 0.97586 | 54.22 | 113.1385514 | 28.06
56.2 |  |  |  | 819 | 116.8122087 | 28.17 | 0.97586
55.93 |  |  |  | 798 | 112.8071301 | 29.03 | 0.97586
55.72 |  |  |  | 777 | 109.8483216 | 29.7 | 0.97586
56.09 |  |  |  | 756 | 108.3880939 | 30.3 | 0.97586 | 54.46 | 103.5298745 | 30.8
55.99 |  |  |  | 735 | 103.6454026 | 31.63 | 0.97586
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

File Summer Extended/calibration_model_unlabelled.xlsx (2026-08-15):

Mass of water (g) | Trial | Steps | Acceleration (steps/sec^2) | Speed (steps/sec) | Flow Rate (ml/min) | Time (sec) | density | syringe volume | Flow rate R2 | time
55.96 |  | 22000 | 200 | 1050 | 146.6016795 | 22.35 | 0.97586 | 55.27 | 143.8287525 | 22.5
55.99 |  |  |  | 1008 | 133.80833 | 24.5 | 0.97586 | 54.99 | 132.4455979 | 24.31
55.88 |  |  |  | 960 | 127.2108635 | 25.72 | 0.97586 |  | #DIV/0!
55.7 |  |  |  | 966 | 133.1152702 | 24.5 | 0.97586 |  | #DIV/0!
55.15 |  |  |  | 942 | 125.6467214 | 25.7 | 0.97586 | 55.57 | 126.1128842 | 25.8
55.89 |  |  |  | 900 | 123.3489983 | 26.53 | 0.97586 |  | #DIV/0!
55.67 |  |  |  | 858 | 118.7023879 | 27.46 | 0.97586 | 55.64 | 119.904712 | 27.17
56.07 |  |  |  | 816 | 116.7077217 | 28.13 | 0.97586 |  | #DIV/0!
56.06 |  |  |  | 774 | 111.267888 | 29.5 | 0.97586 |  | #DIV/0!
56 |  |  |  | 732 | 105.3289303 | 31.13 | 0.97586 | 54.86 | 101.329362 | 31.7
56.08 |  |  |  | 690 | 99.05199783 | 33.15 | 0.97586 |  | #DIV/0!
55.88 |  |  |  | 648 | 95.13996534 | 34.39 | 0.97586 | 55.26 | 92.41820668 | 35.01
52.92 |  |  |  | 606 | 91.89058932 | 33.72 | 0.97586 |  | #DIV/0!
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

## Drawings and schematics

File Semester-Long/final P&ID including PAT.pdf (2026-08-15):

## Water

## Sodium

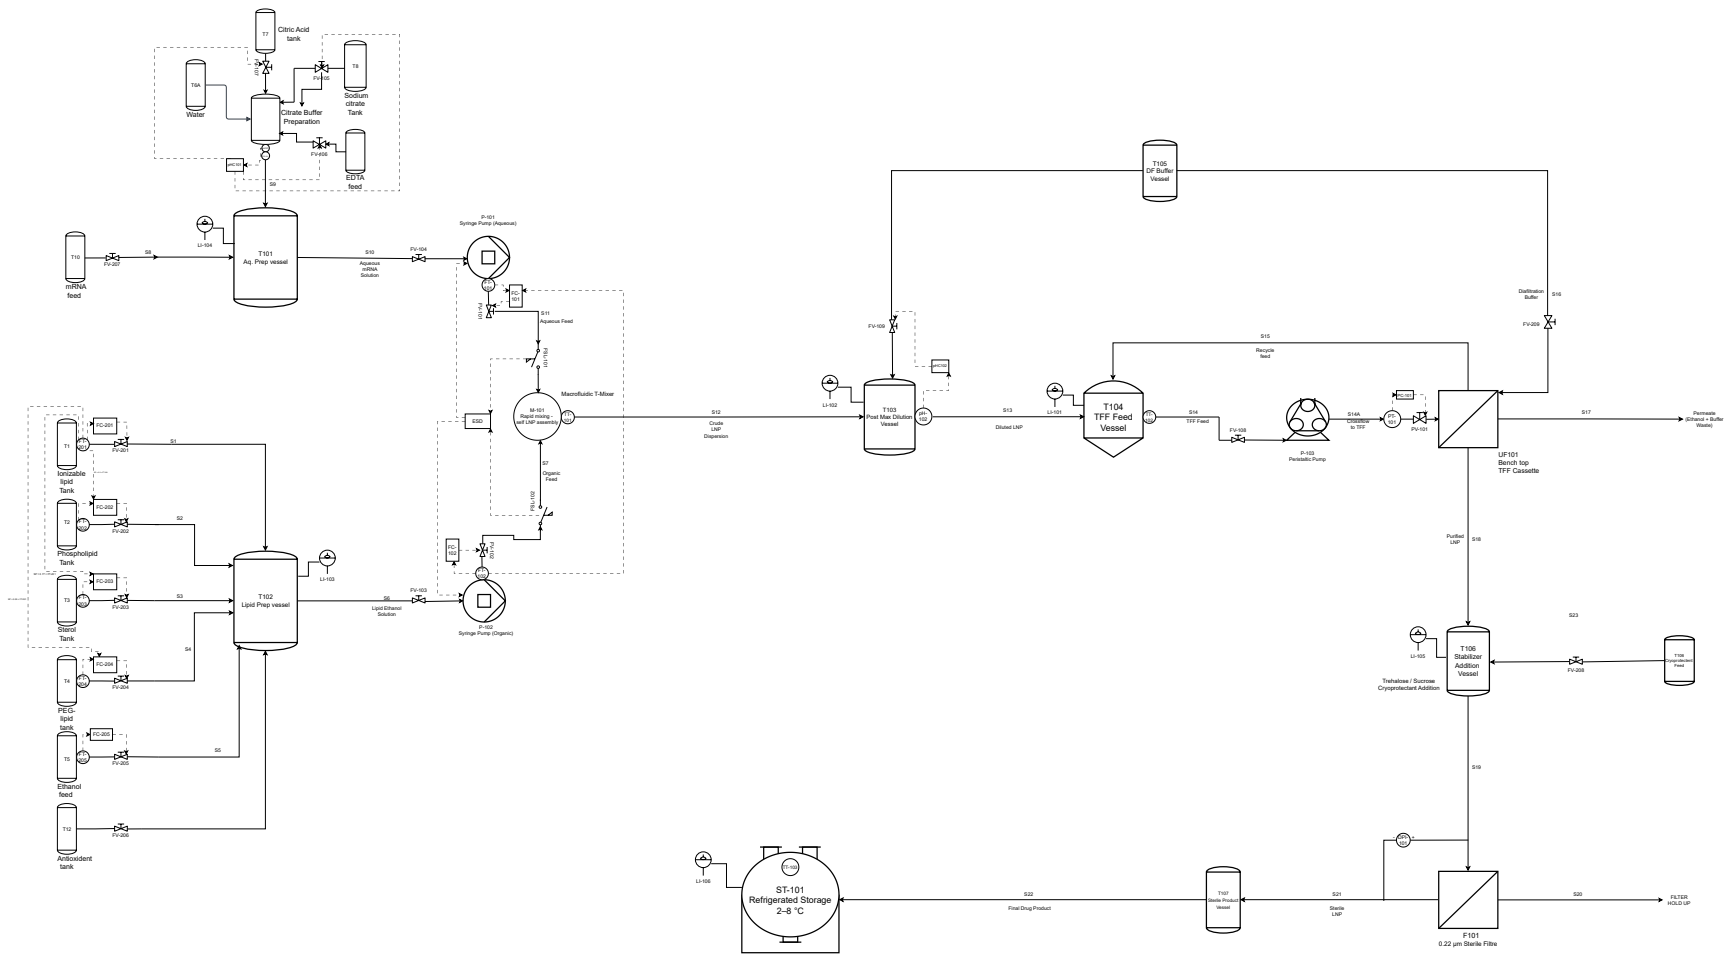
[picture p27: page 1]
citrate Tank; Citric Acid tank; Citrate Buffer Preparation; EDTA feed; Antioxident tank; PEG- lipid tank; Phospholipid Tank; Ionizable lipid Tank; Ethanol feed; Sterol Tank; mRNA feed; T103 Post Max Dilution Vessel; T105 DF Buffer Vessel; T104 TFF Feed Vessel; UF101 Bench top TFF Cassette; Permeate (Ethanol + Buffer Waste); T106 Stabilizer Addition Vessel; T107 Sterile Product Vessel; ST-101 Refrigerated Storage 2–8 °C; FILTER; HOLD UP; Aqueous mRNA Solution; Aqueous Feed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

Syringe Pump (Aqueous)

Aq. Prep vessel

self LNP assembly FSL-101 FSL⁻102

Lipid Prep vessel

Syringe Pump (Organic)

Final Drug Product

0.22 µm Sterile Filtre

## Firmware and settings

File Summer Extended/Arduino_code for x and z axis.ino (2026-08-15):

// CNC Shield V3 - X & Z Move Only One Direction (120 mm)

#include <AccelStepper.h>

#define X_STEP_PIN 2
#define X_DIR_PIN  5
#define Z_STEP_PIN 4
#define Z_DIR_PIN  7
#define EN_PIN     8

AccelStepper stepperX(AccelStepper::DRIVER, X_STEP_PIN, X_DIR_PIN);
AccelStepper stepperZ(AccelStepper::DRIVER, Z_STEP_PIN, Z_DIR_PIN);

const long STEPS_TO_MOVE = 22000;   // 90 mm moving distance
const float MAX_SPEED = 1050.0;     // steps/sec
const float ACCEL = 200.0;          // steps/sec²

void setup()
{
  pinMode(EN_PIN, OUTPUT);
  digitalWrite(EN_PIN, LOW);   // Enable drivers

  stepperX.setMaxSpeed(MAX_SPEED);
  stepperX.setAcceleration(ACCEL);

  stepperZ.setMaxSpeed(MAX_SPEED);
  stepperZ.setAcceleration(ACCEL);

  // Move only once in one direction
  stepperX.move(STEPS_TO_MOVE);
  stepperZ.move(STEPS_TO_MOVE);
}

void loop()
{
  // Keep running until both motors reach the target
  if (stepperX.distanceToGo() != 0 || stepperZ.distanceToGo() != 0)
  {
    stepperX.run();
    stepperZ.run();
  }
  else
  {
    // Motion complete - stop here
    while (1);
  }
}
